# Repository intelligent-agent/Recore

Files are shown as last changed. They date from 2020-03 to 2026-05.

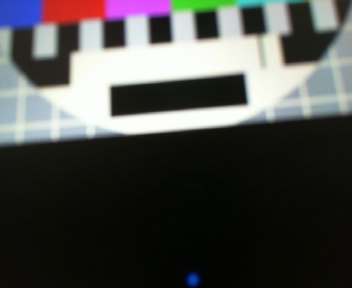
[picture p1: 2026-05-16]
Calibrations/Recore_A8_0449/test_picture.jpg

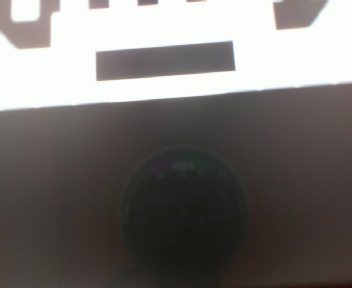
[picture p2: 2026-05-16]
Calibrations/Recore_A8_0461/test_picture.jpg

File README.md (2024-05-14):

# Recore
Repository for Recore 3D printer control board

## What is in here?
- Schematics for Recore etc.
- 3D models of Recore
- Device tree sources
- Special binaries for booting the board in FEL mode
- Calibration and testing data from the manufacturing process

## Note about binaries
There are binaries for booting the board in FEL mode with a
USB drive insered. This method bypasses the eMMC completely.
The three files
- sunxi-spl.bin
- bl31.bin
- u-boot.bin

are used to boot a board in FEL mode. See Makefile
for instructions to use those for a specific revision.

The file `configs/recore_fel_config` is used to compile the new u-boot binaries, 
it is based on u-boot-v2022.07. 

## Sources
The binaries are identical to the what is used in Refactor/Rebuild distro,
the source code is available here:  
https://github.com/intelligent-agent/u-boot and  
https://github.com/intelligent-agent/arm-trusted-firmware  
The only differece is the boot command. In the stock image:  
`run distro_bootcmd`  
in the FEL binaries:   
`run bootcmd_usb0`

## Installing the sunxi-tools package. 
In order to boot the board from FEL-mode, the program `sunxi-fel` must be available. 
In recent versions of Debian (Bookworm and later) and derivatives, this can be installed from apt. 
```
sudo apt install sunxi-tools
```
On older versions of Debian, the sunxi-tools package does not have support for Allwinner A64. 
If that is the case, the program can be downloaded and installed with these instructions:
```
git clone https://github.com/linux-sunxi/sunxi-tools
cd sunxi-tools
make
sudo make install
```

## Starting the board in FEL-mode
Hold down the button marked `fel` while applying power.
The PMIC/power LED should come on. The board must be connected to a host computer through the USB C connector. When the board is in FEL-mode, it should show up as
a USB device on the host computer:  
`lsusb`  
should show:  
`Allwinner Technology sunxi SoC OTG connector in FEL/flashing mode`

Then use the Makefile to run:  
`make fel`

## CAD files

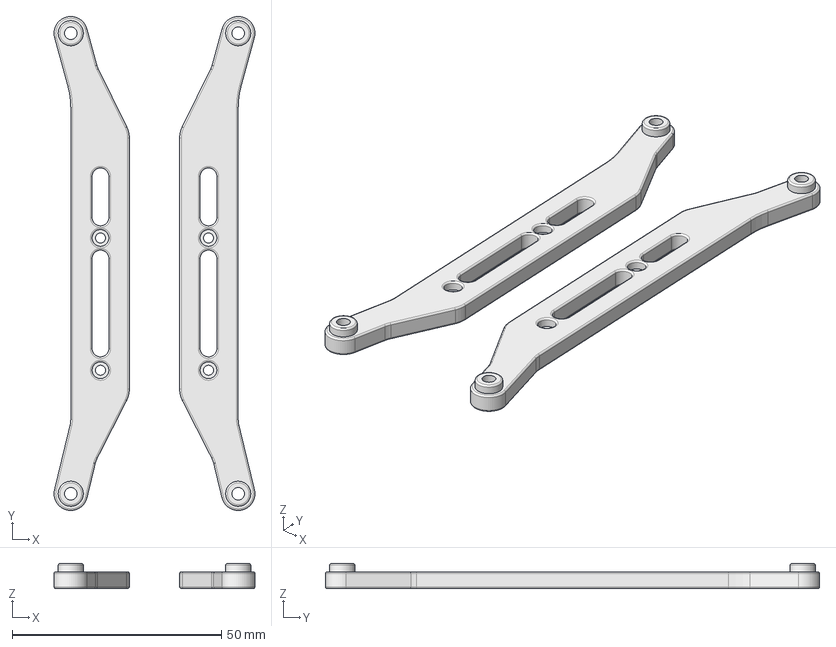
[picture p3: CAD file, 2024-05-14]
3D-files/Rebase/Rebase_A0_din-rail-holders.step
48.0 x 118.0 x 6.00 mm

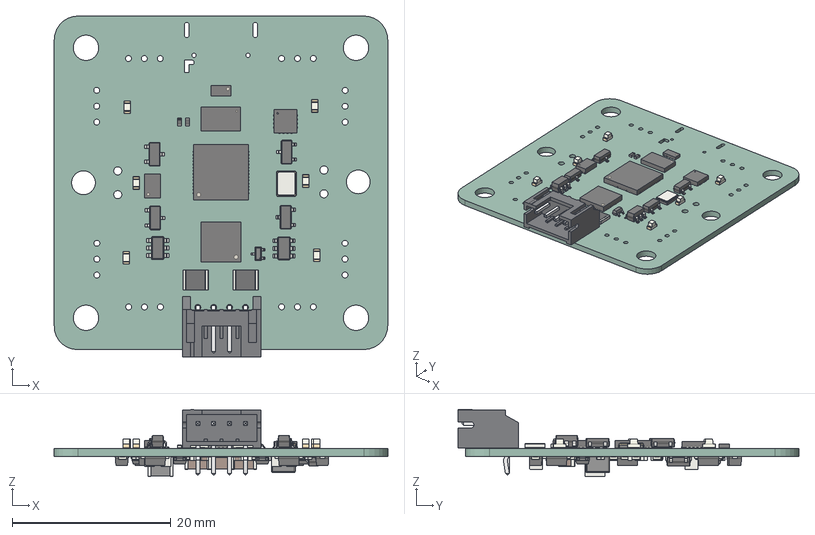
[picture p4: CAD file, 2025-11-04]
3D-files/Retool_A2.step
42.0 x 42.9 x 8.45 mm
DFN-8-1EP_3x2mm_P0.5mm_EP1.7x1.6mm
QFN-56-1EP_7x7mm_Pitch0.4mm
Crystal_SMD_3225-4Pin_3.2x2.5mm
LED_0603_1608Metric x 6
JST_S4B_PH_K
LGA_14_3x5mm_P08mm_LayoutBorder1x6y
R_0402_1005Metric x 42
R_1210_3225Metric x 3
QFN-28-1EP_5x5mm_Pitch0.5mm
SOT_23 x 5
SOT_23_6 x 2
WQFN_16_1EP_3x3mm_P05mm_EP16x16mm
UDFN_10_135x26mm_Pitch05mm
C_1206_3216Metric x 3
C_0402_1005Metric x 37
C_0805_2012Metric x 4
D_SOD_123F x 9
SOT_563
L_Wuerth_MAPI_3020
L_1210_3225Metric
Retool_PCB

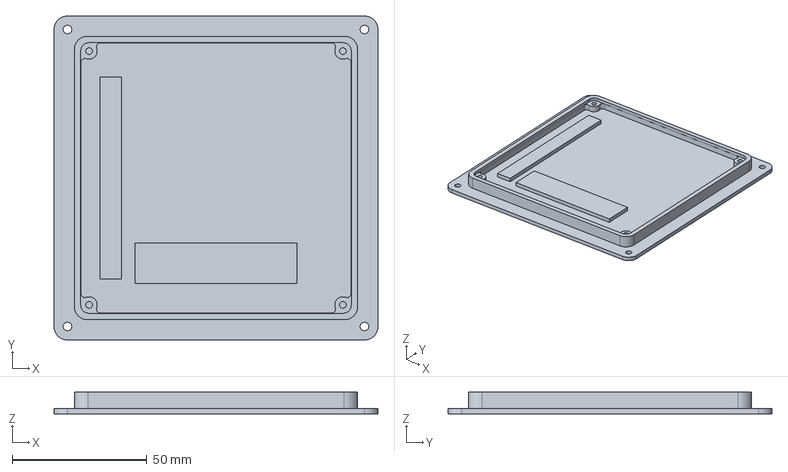
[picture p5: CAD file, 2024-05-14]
3D-files/Rebase/Rebase_A0.step
120.0 x 120.0 x 8.00 mm

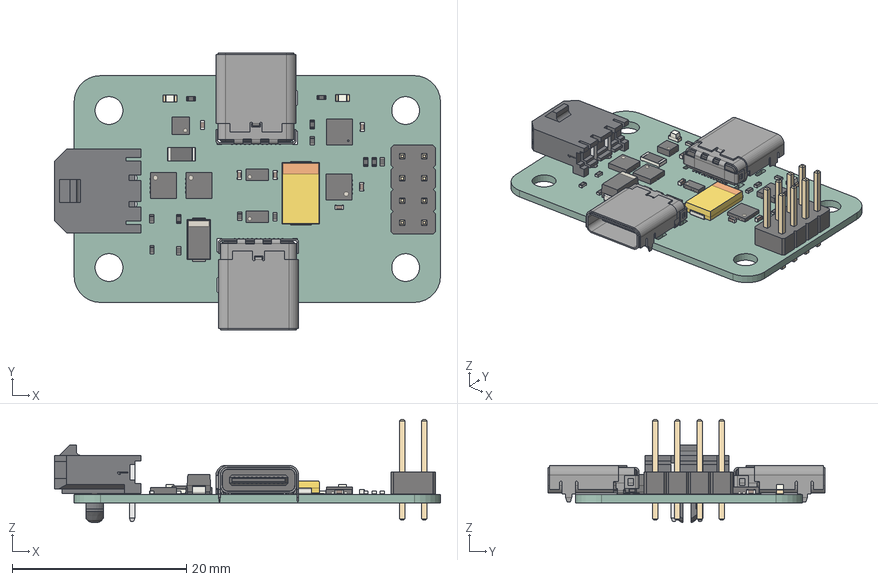
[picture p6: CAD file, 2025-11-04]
3D-files/Resend_A2.step
44.2 x 31.8 x 11.8 mm
C_0402_1005Metric x 6
LED_0603_1608Metric x 2
DFN-8-1EP_3x3mm_Pitch0.5mm x 2
UDFN_10_135x26mm_Pitch05mm x 2
R_0402_1005Metric x 13
WQFN_16_1EP_3x3mm_P05mm_EP16x16mm
DFN-8-1EP_2x2mm_Pitch0.5mm
USB_C_Receptacle_Amphenol_12401610E4-2A x 2
PinHeader_2x04_P254mm_Vertical
R_1206_3216Metric
UQFN-16-1EP_3x3mm_Pitch0.5mm
CP_EIA_7343_15_Kemet_W
D_SMA
_autosave-Resend_PCB

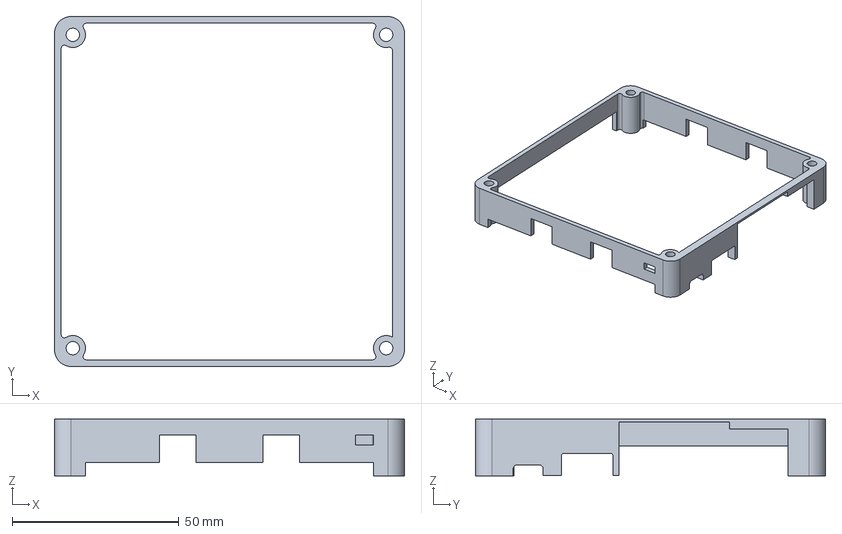
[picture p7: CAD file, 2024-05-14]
3D-files/Rebase/Rebase_A0-ABS-cover.step
105.0 x 105.0 x 17.0 mm

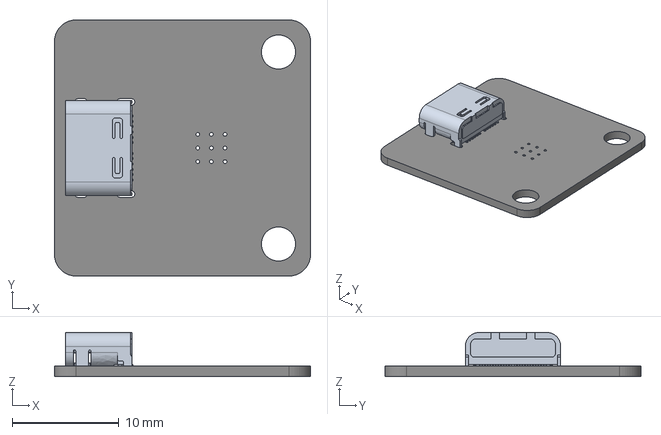
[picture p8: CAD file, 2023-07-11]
3D-files/Remove_A1.step
24.0 x 24.0 x 4.13 mm
Remove_A1 PCB

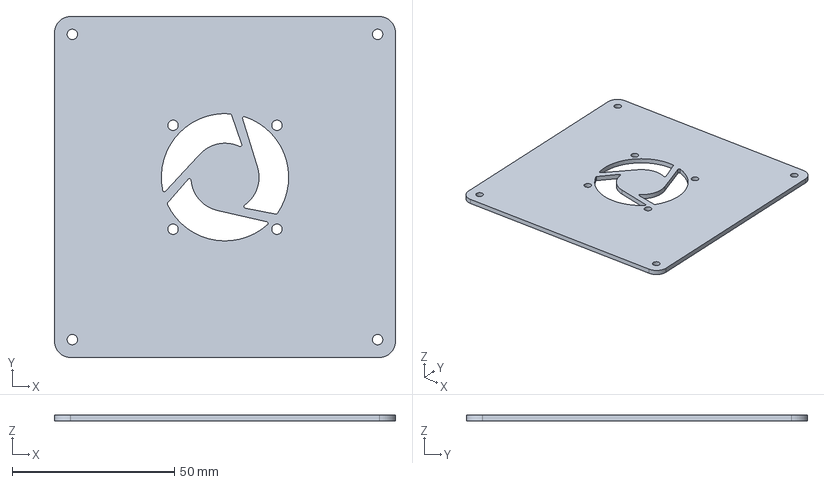
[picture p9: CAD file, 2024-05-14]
3D-files/Rebase/Rebase_A0-acrylic-lid.step
105.0 x 105.0 x 2.00 mm

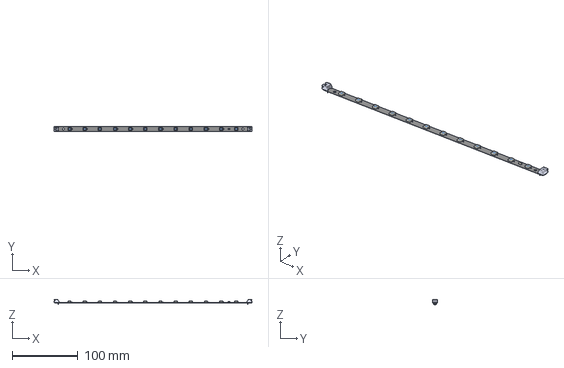
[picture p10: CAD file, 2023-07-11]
3D-files/Relit_A0.step
301.0 x 8.01 x 8.20 mm
_autosave-Relit_A0 PCB

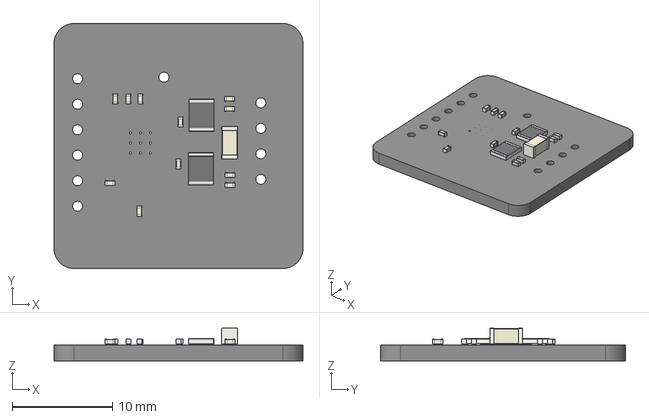
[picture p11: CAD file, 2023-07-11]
3D-files/Restep_A1.step
24.8 x 24.4 x 3.25 mm
Restep_A1 PCB

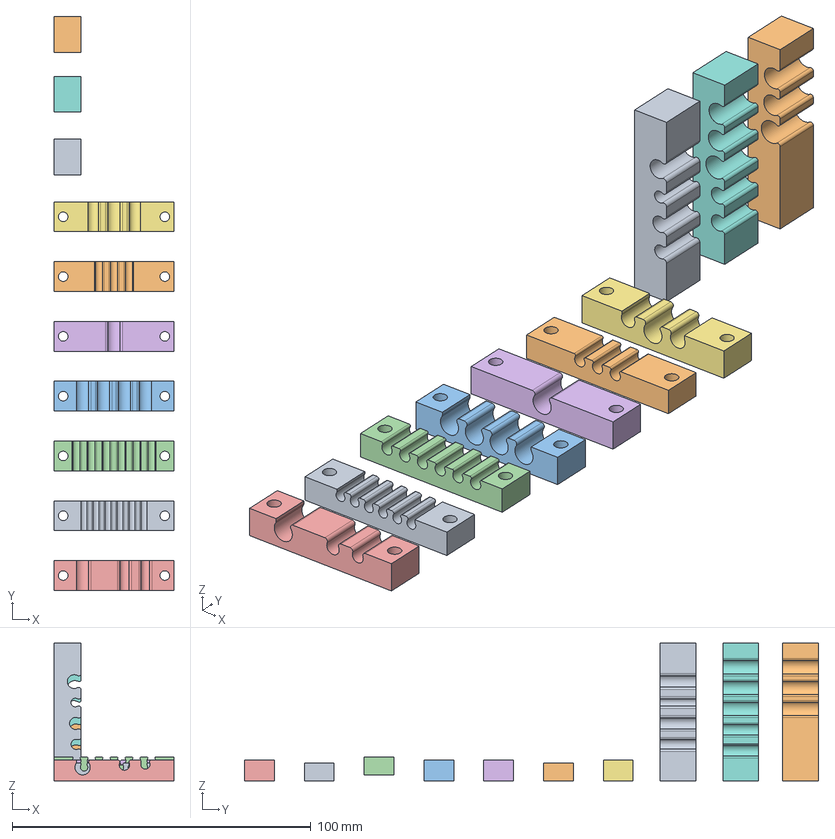
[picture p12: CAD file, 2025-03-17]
3D-files/Voron-2.4/Clamps/Clamps.FCStd
40.0 x 192.0 x 46.0 mm
Wires-6-24V
Wires-3-220V
Steppers-4-wires
Wires-6-220V
Wires-Stepper-camera-Relit
Wires-Stepper
Wires-back
Wires-3xUSB-2xFan-Eth
Wires-2xUSB-HDMI-2xFan
Wires-USB-USB-Eth

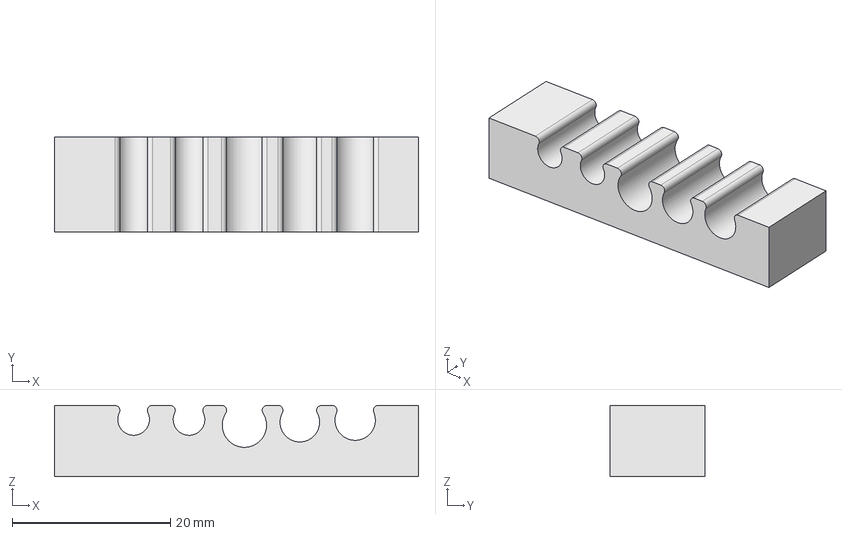
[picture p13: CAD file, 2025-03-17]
3D-files/Voron-2.4/Clamps/Wires-3xUSB-2xFan-Eth.step
46.0 x 12.0 x 9.00 mm

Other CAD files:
3D-files/Voron-2.4/Clamps/Wires-2xUSB-HDMI-2xFan.step
3D-files/Voron-2.4/Clamps/Wires-USB-USB-Etht.step

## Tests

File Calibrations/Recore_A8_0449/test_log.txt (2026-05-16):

Test starting 2026-03-01 22:23:06.269564
Testing board
Board voltage           [    OK   ]
Current                 [    OK   ]
Board t                 [    OK   ]
Junction t              [    OK   ]
Similarity              [    OK   ]
Thermistor Off voltage  [    OK   ]
Thermistor On voltage   [    OK   ]
ES1 Off voltage         [    OK   ]
ES1 On voltage          [    OK   ]
ES0 off voltage         [    OK   ]
ES0 on voltage          [    OK   ]
ES0 12V value           [    OK   ]
USB host 0 on           [    OK   ]
USB host 1 on           [    OK   ]
USB host 2 on           [    OK   ]
USB host 3 on           [    OK   ]
FEL voltage             [    OK   ]
BOOT voltage            [    OK   ]
RESET voltage           [    OK   ]
HDMI voltage            [    OK   ]
V-HP off                [    OK   ]
Testing motors
Stepper 0 comm          [    OK   ]
Stepper 1 comm          [    OK   ]
Stepper 2 comm          [    OK   ]
Stepper 3 comm          [    OK   ]
Stepper 4 comm          [    OK   ]
Stepper 5 comm          [    OK   ]
Stepper 0 driver        [    OK   ]
Stepper 1 driver        [    OK   ]
Stepper 2 driver        [    OK   ]
Stepper 3 driver        [    OK   ]
Stepper 4 driver        [    OK   ]
Stepper 5 driver        [    OK   ]
Testing heaters
Heater H0 on            [    OK   ]
Heater H0 off           [    OK   ]
Heater H1 on            [    OK   ]
Heater H1 off           [    OK   ]
Heater H2 on            [    OK   ]
Heater H2 off           [    OK   ]
Heater BED on           [    OK   ]
Heater BED off          [    OK   ]
Heater Fan 0 on         [    OK   ]
Heater Fan 0 off        [    OK   ]
Heater Fan 1 on         [    OK   ]
Heater Fan 1 off        [    OK   ]
Heater Fan 2 on         [    OK   ]
Heater Fan 2 off        [    OK   ]
Heater Fan 3 on         [    OK   ]
Heater Fan 3 off        [    OK   ]
Testing USB
Devices                 [    OK   ]
USB host 0 on           [    OK   ]
USB host 1 on           [    OK   ]
USB host 2 on           [    OK   ]
USB host 3 on           [    OK   ]
Testing Ethernet
Ethernet                [    OK   ]
Testing voltages
VS                      [    OK   ]
GND BOARD               [    OK   ]
12V JIG                 [    OK   ]
GND JIG                 [    OK   ]
V HP                    [    OK   ]
3.3V_VREF               [    OK   ]
1.05V_ETH               [    OK   ]
3.3V_AREF               [    OK   ]
ADC-V                   [    OK   ]
ADC-T                   [    OK   ]
ADC-I                   [    OK   ]
0.6V_CMPREF             [    OK   ]
1.8-VINT                [    OK   ]
3.3V-VA                 [    OK   ]
3.0V-PLL                [    OK   ]
3.0V-RTC                [    OK   ]
+12V                    [    OK   ]
1.1V-CPUS               [    OK   ]
1.25V-VREF              [    OK   ]
1.2V-CPUX               [    OK   ]
1.35V-DDR3              [    OK   ]
1.8V-EMMC               [    OK   ]
3.3-HDMI                [    OK   ]
1.1V-SYS                [    OK   ]
+5V                     [    OK   ]
3.3V                    [    OK   ]
VS                      [    OK   ]
Testing op-amp offset
Opamp T0, offset on     [    OK   ]
Opamp T0, offset off    [    OK   ]
Opamp T1, offset on     [    OK   ]
Opamp T1, offset off    [    OK   ]
Opamp T2, offset on     [    OK   ]
Opamp T2, offset off    [    OK   ]
Opamp T3, offset on     [    OK   ]
Opamp T3, offset off    [    OK   ]
Testing op-amp gain
Opamp T0, gain 1        [    OK   ]
Opamp T0, offset 0.0002 [    OK   ]
ADC diff T0 is 0.025    [    OK   ]
Opamp T0, gain 100      [    OK   ]
Opamp T0, offset 0.33   [    OK   ]
ADC diff T0 is 0.025    [    OK   ]
Opamp T1, gain 1        [    OK   ]
Opamp T1, offset 0.0002 [    OK   ]
ADC diff T1 is 0.025    [    OK   ]
Opamp T1, gain 100      [    OK   ]
Opamp T1, offset 0.33   [    OK   ]
ADC diff T1 is 0.025    [    OK   ]
Opamp T2, gain 1        [    OK   ]
Opamp T2, offset 0.0002 [    OK   ]
ADC diff T2 is 0.025    [    OK   ]
Opamp T2, gain 100      [    OK   ]
Opamp T2, offset 0.33   [    OK   ]
ADC diff T2 is 0.025    [    OK   ]
Opamp T3, gain 1        [    OK   ]
Opamp T3, offset 0.0002 [    OK   ]
ADC diff T3 is 0.025    [    OK   ]
Opamp T3, gain 100      [    OK   ]
Opamp T3, offset 0.33   [    OK   ]
ADC diff T3 is 0.025    [    OK   ]
Testing op-amp resistors
Resistor T0 pull-up     [    OK   ]
Resistor T0 offset      [    OK   ]
Resistor T1 pull-up     [    OK   ]
Resistor T1 offset      [    OK   ]
Resistor T2 pull-up     [    OK   ]
Resistor T2 offset      [    OK   ]
Resistor T3 pull-up     [    OK   ]
Resistor T3 offset      [    OK   ]
Testing Recore
Recore                  [    OK   ]

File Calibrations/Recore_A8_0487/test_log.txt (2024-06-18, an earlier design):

Test starting 2024-06-18 20:45:25.012450
Testing board
Board voltage           [    OK   ]

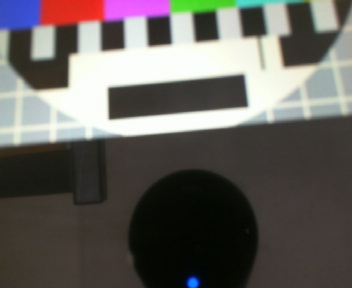
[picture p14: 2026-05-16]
Calibrations/Recore_A8_0453/test_picture.jpg

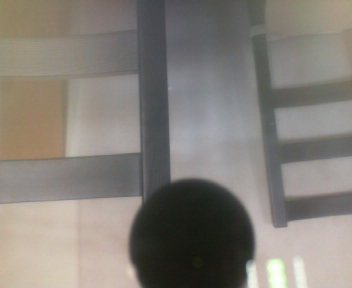
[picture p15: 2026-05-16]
Calibrations/Recore_A8_0452/test_picture.jpg

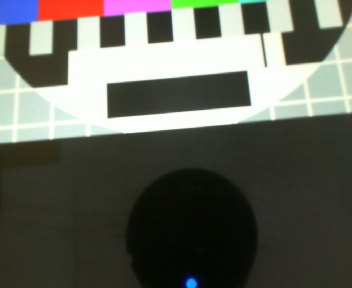
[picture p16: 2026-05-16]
Calibrations/Recore_A8_0466/test_picture.jpg

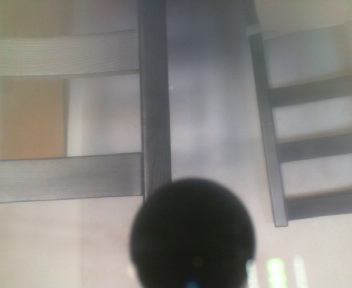
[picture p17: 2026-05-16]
Calibrations/Recore_A8_0460/test_picture.jpg

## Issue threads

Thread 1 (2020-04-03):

Assistance Desired?

Casey7747, 2020-04-03:
Hi Elias,
I have been following your revolve project as I am in the process of putting a new printer together and hoped to use your controller.

How are you traveling with the latest iteration, Recore? Would you like some help?
I am very familiar with Linux, python programming/scripting + arduino + elec design at a hobby level. I am an automation engineer by profession designing programming PLC etc. So I may be of some help.

I would think helping you in testing would be my greatest assistance but I don't think you are there yet. I can also do debugging and maybe simulations?

Let me know if you think I could help.

Regards
Felix

eliasbakken, 2020-04-04:
Hi Felix! Thanks a lot for your enthusiasm : )

To answer your question: Yes, help is needed, but it's really on the software side that you can contribute. I've put together a couple of boards so far, that are intended for some of the people that have been in the (replicape) community for a long time, so they have dibs. I'm hoping to get a small batch of around ten boards made based on their feedback and my own testing.

I'm planning to sell the first 10 board batch for a normal price, so it's really intedid for those with a special interest in early access to the hardware. Later batches will have better software support and probably some hardware changes as well.

Those Rev A2 boards should be going out this week, and we discuss most of the details in #development channel on replicape.slack.com

Casey7747, 2020-04-05:
Thanks,
I have emailed you re: slack.

Closed 2020-04-05.

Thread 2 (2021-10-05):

CAD model discrepancies

eliasbakken, 2021-10-05:
The USB is 1 mm too high and the HDMI is 1 mm loo low.

eliasbakken, 2022-01-13:
The model has been updated and should be pretty accurate. I measured the height of the USB and HDMI, but only adjusted the HDMI with 0.5 mm.

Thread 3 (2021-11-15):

Hello and Setting the Recore for Printing on the Older Model Printer I have Currently...

silver2row, 2021-11-15:
Hello,

Seth here. @eliasbakken and @goeland86 , this is Seth or known as silver2row on support-recore on Discord.

Anyway, enough w/ names for now.

Can I use the 12v pin on ES0 when using GND and 3.3v on the ES5 pin specifically for the NPN Probe I use?

I am asking b/c I did not know if there was a bridge or bar of a GND on that specific side of the Recore. I do not want to catch static or error when trying to wire up like this idea on the Recore. If this does not make sense, I completely understand. I can try to better make sense in time.

...

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

...

I see where the ES0 connection on the wiki is 5v/12v and can be picked to either/or. But, in the photo I have listed, the ES5 pin is listed as 5v/12v.

I just want to make sure I do not alter the board state permanently by applying GND to a pin outside of its specific connector area.

Seth

P.S. Please do let me know what you have in mind from this issue. I contacted the group on Discord already. If Discord is a better place to handle this issue, that is okay too. I will just wait and try to catch someone.

eliasbakken, 2021-11-15:
Hi Seth,
Discord is probably better for support issues like this. This issue tracker is meant for hardware bugs with Recore boards specifically.  The numbering of the end stops were changed at some point during the development, so I think ES5 switched places with ES0 and so on. So The pinout information in the picture on the wiki is outdated. It is ES0 that has the programmable 5/12V output.

To answer your question, the ground of all the end stops are connected together. so you can use the 12V on EN0 for triggering the input on ES5 for instance. But there should be the right number of of pins to mount an inductive sensor using only ES0.
You mention 3.3V on the ES5, that is not correct. The output is fixed at 5V. So just be aware of that when wiring up.

silver2row, 2021-11-15:
Hello,

Thank you for this update. And okay about the 5v output on ES5. My mistake.

Seth

Closed 2021-11-15.

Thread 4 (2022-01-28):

Add an LED close to the USB hub/connectors to indicate activitiy on the USB.

eliasbakken, 2022-01-28:
On rev A6, the user LED close to the HDMI connector is used to indicate activity on the USB hosts. This is not ideal, since the position of the LED is not related to the function. It would be better if the LED was close to the USB hub chip to match the pattern shown by the other chips.

eliasbakken, 2023-06-28:
This has been fixed on A7.

Closed 2023-06-28.

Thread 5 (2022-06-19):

Recore din rail .step file

Jasontwd, 2022-06-19:
Fusion 360 recore mount and din rail clips if any one needs.  https://a360.co/3N5ySeC

Jasontwd, 2022-06-23:
@tehmaze Hey mate, yes not sure why was not working but is now. Download top right screen.
Lets know if not and I'll email you it.. jason@formtech.co.nz

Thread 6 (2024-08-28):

[Question] What software made this pinout photo?

DjordjeMandic, 2024-08-28:
Hi, im intrested which software did you use to create this pinout photo and other wiring diagrams?

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

eliasbakken, 2024-08-28:
The board is exported from Kicad as step, then imported to Freecad where it is made into a picture and exported as png, then imported to Inkscape where the lables are added.

DjordjeMandic, 2024-08-28:
Thanks, I thought you used something like WireViz or qelectrotech

Closed 2024-08-28.

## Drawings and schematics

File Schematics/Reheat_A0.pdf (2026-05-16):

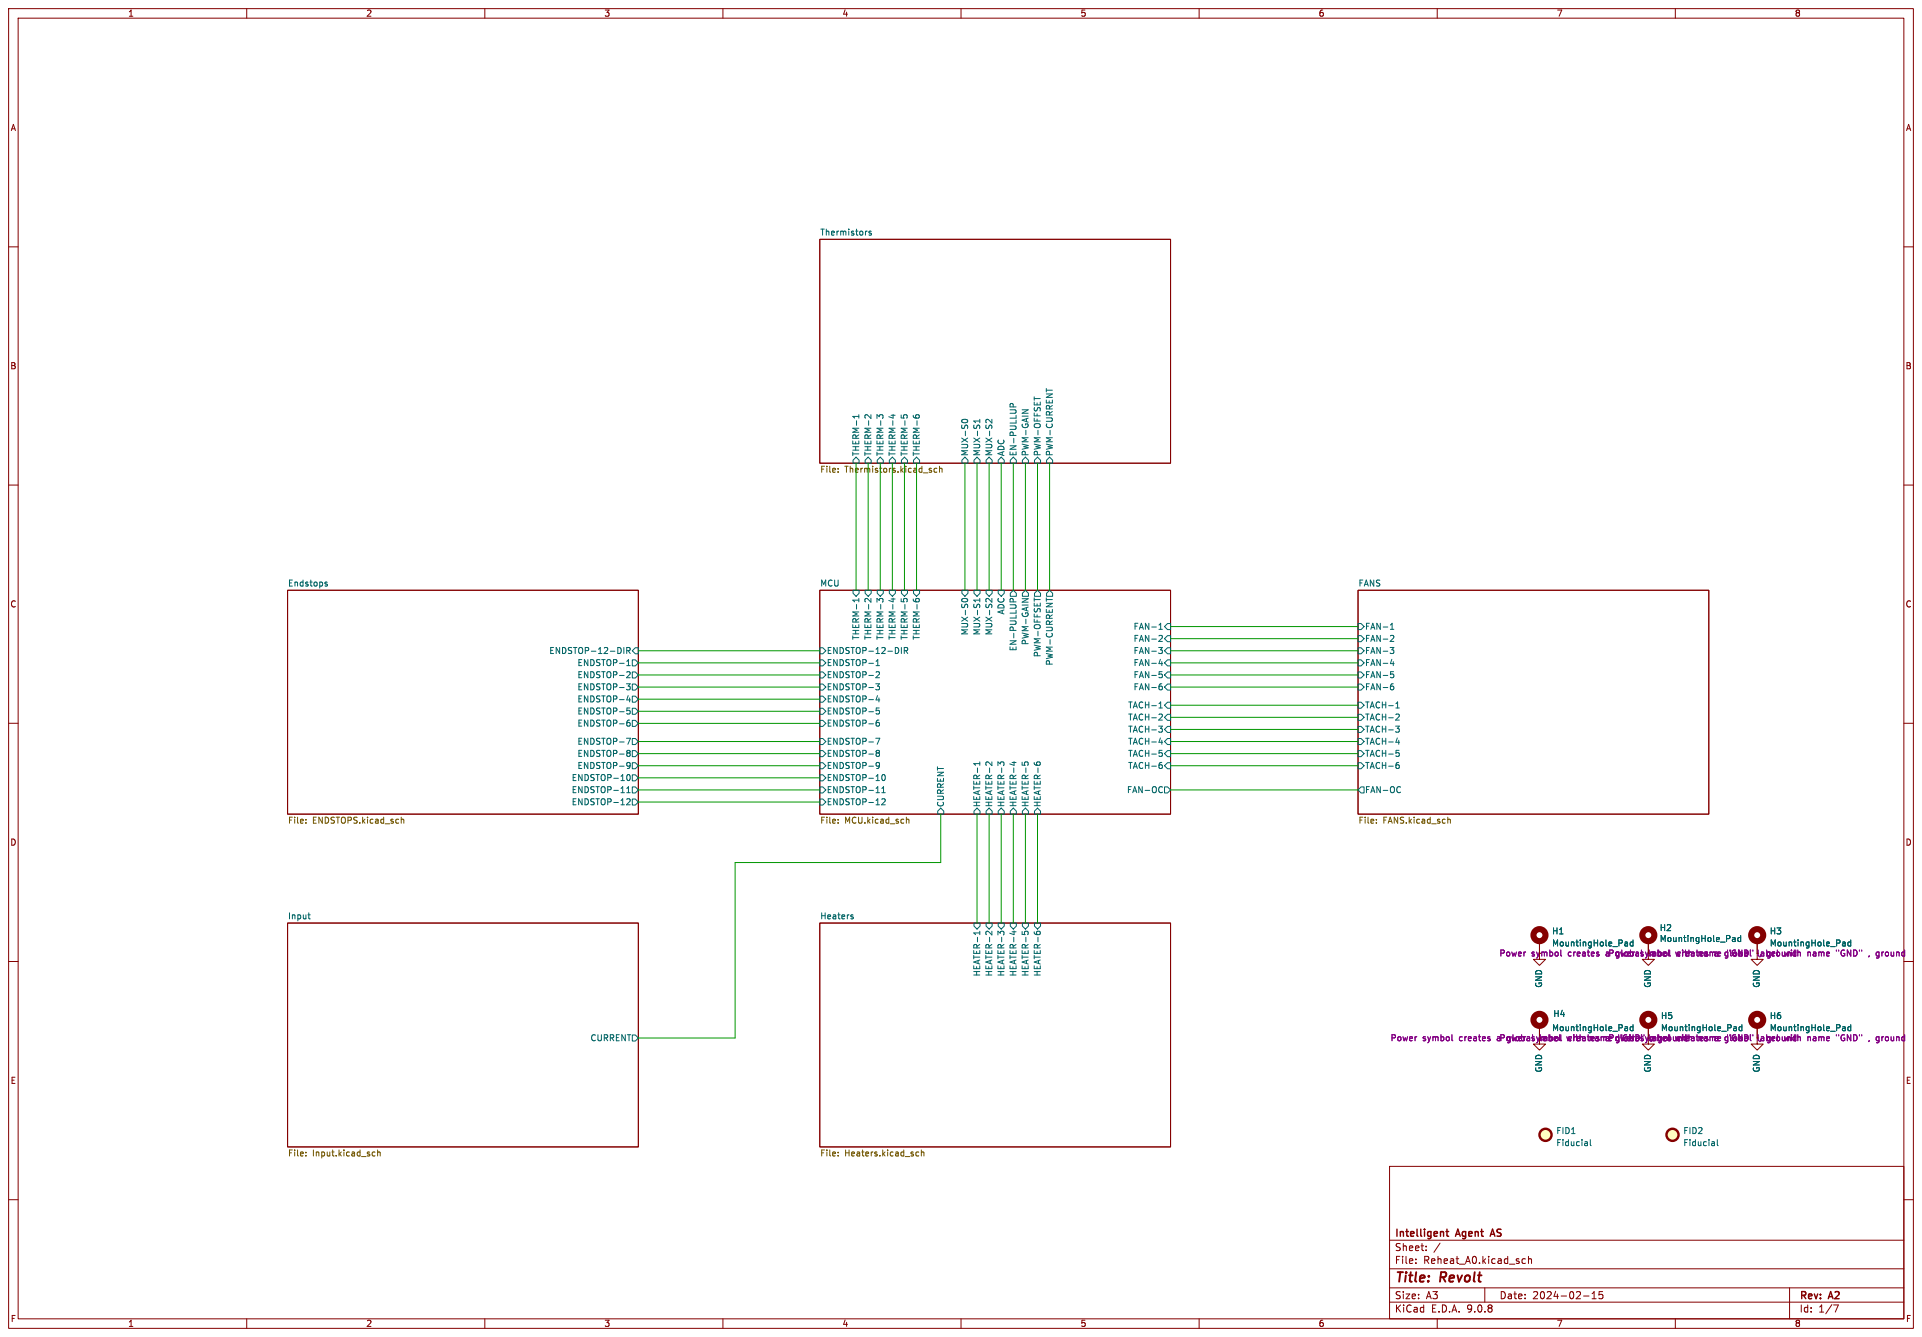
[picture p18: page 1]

ENDSTOP-8 ENDSTOP-6 ENDSTOP-9 ENDSTOP-11 ENDSTOP-7 ENDSTOP-4 ENDSTOP-10 ENDSTOP-3 ENDSTOP-1 ENDSTOP-12 ENDSTOP-5 ENDSTOP-2 ENDSTOP-12-DIR

Power symbol creates a global label with name "GND" , ground H3 MountingHole_Pad H6 MountingHole_Pad GND

Power symbol creates a global label with name "GND" , ground GND GND

Power symbol creates a global label with name "GND" , ground GND

Power symbol creates a global label with name "GND" , ground

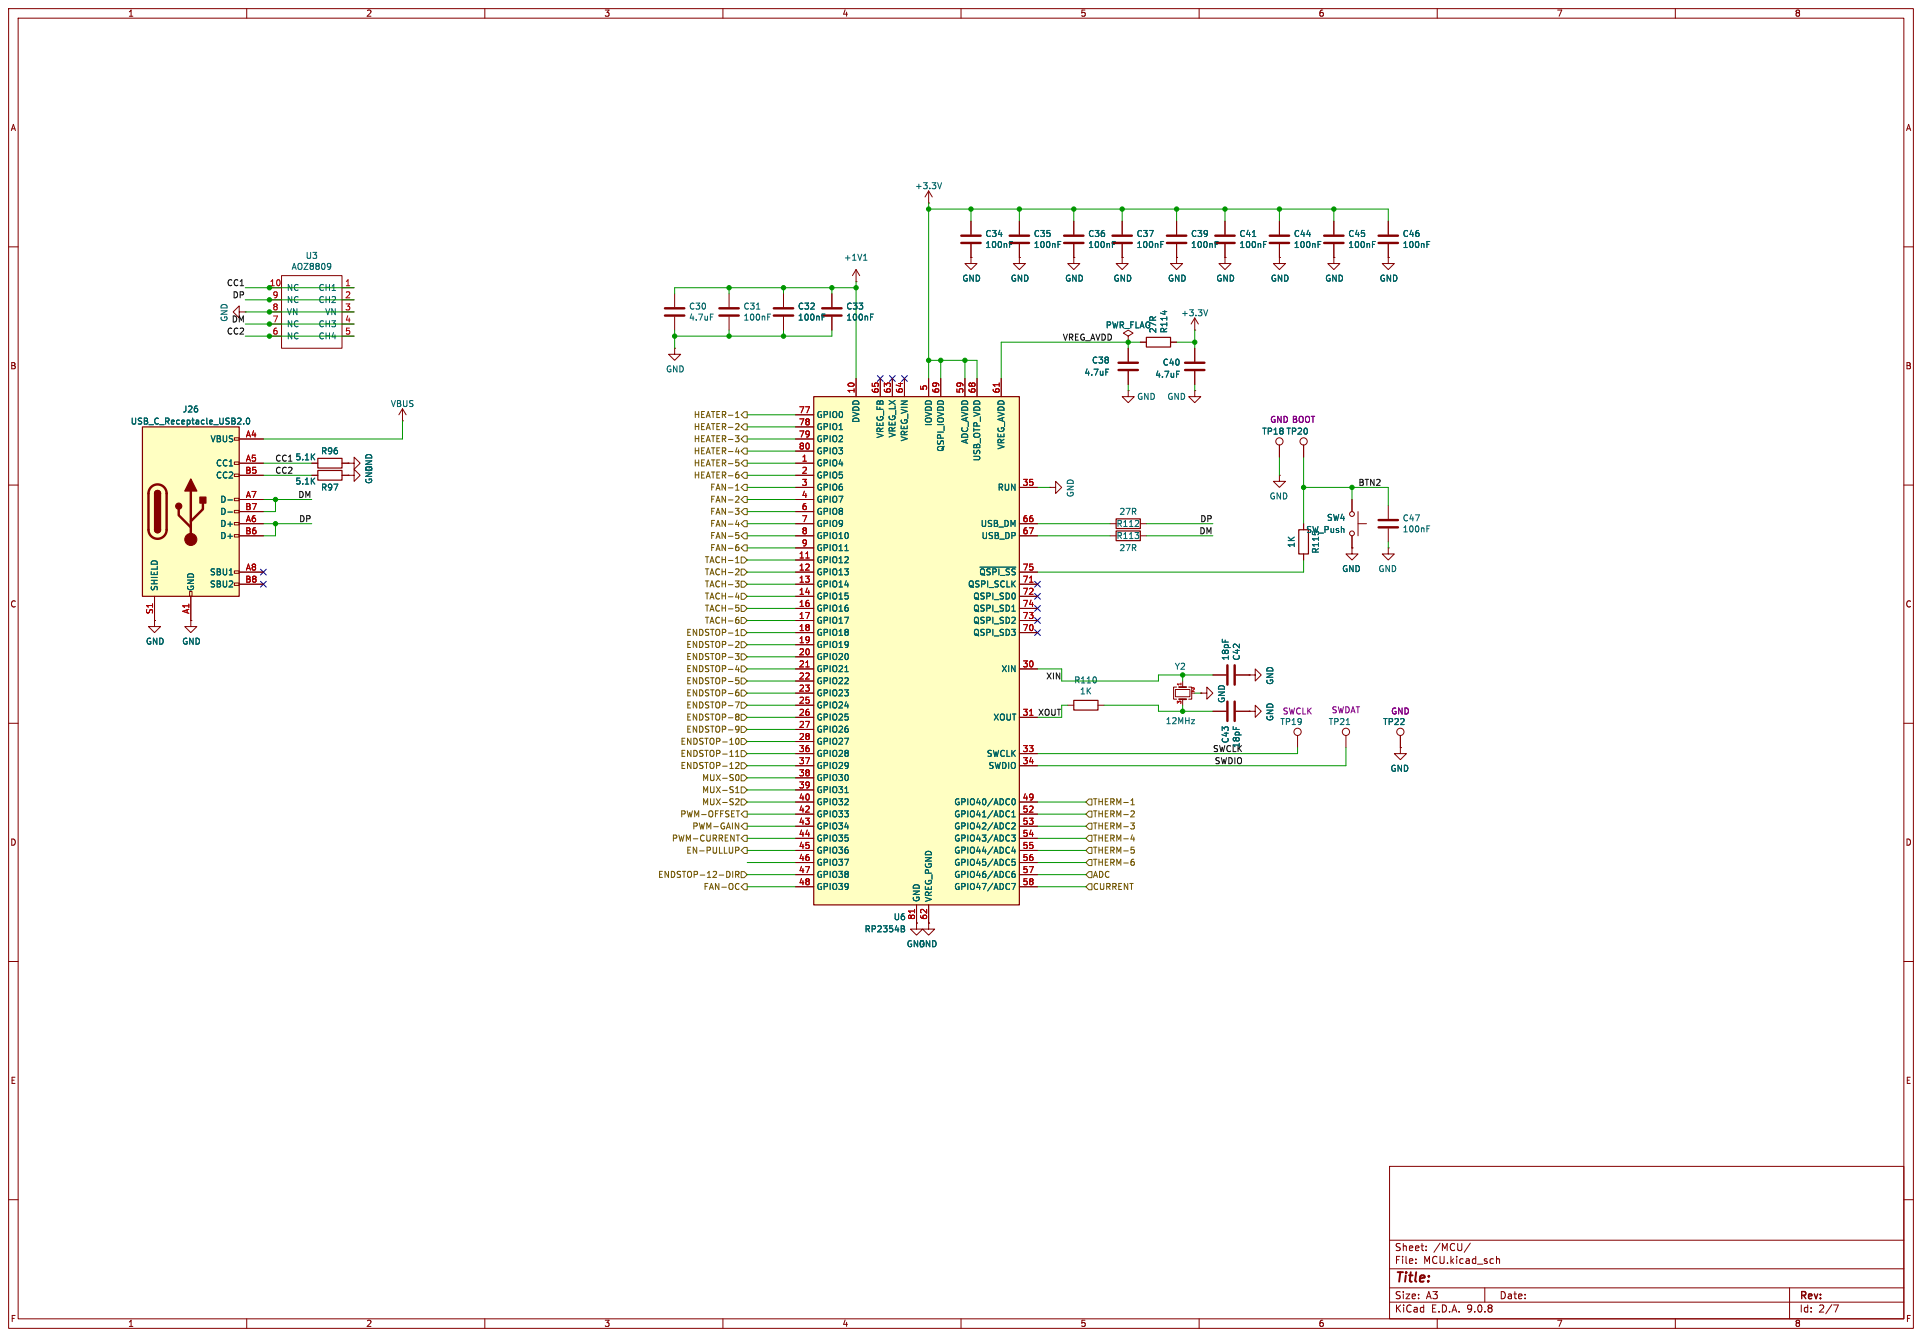
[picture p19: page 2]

TP22 GND GND GND C43 18pF GND

FAN-3 FAN-5 TACH-2 FAN-4 FAN-OC

THERM-4 MUX-S0 PWM-GAIN MUX-S2 MUX-S1 PWM-CURRENT

THERM-3 PWM-OFFSET EN-PULLUP

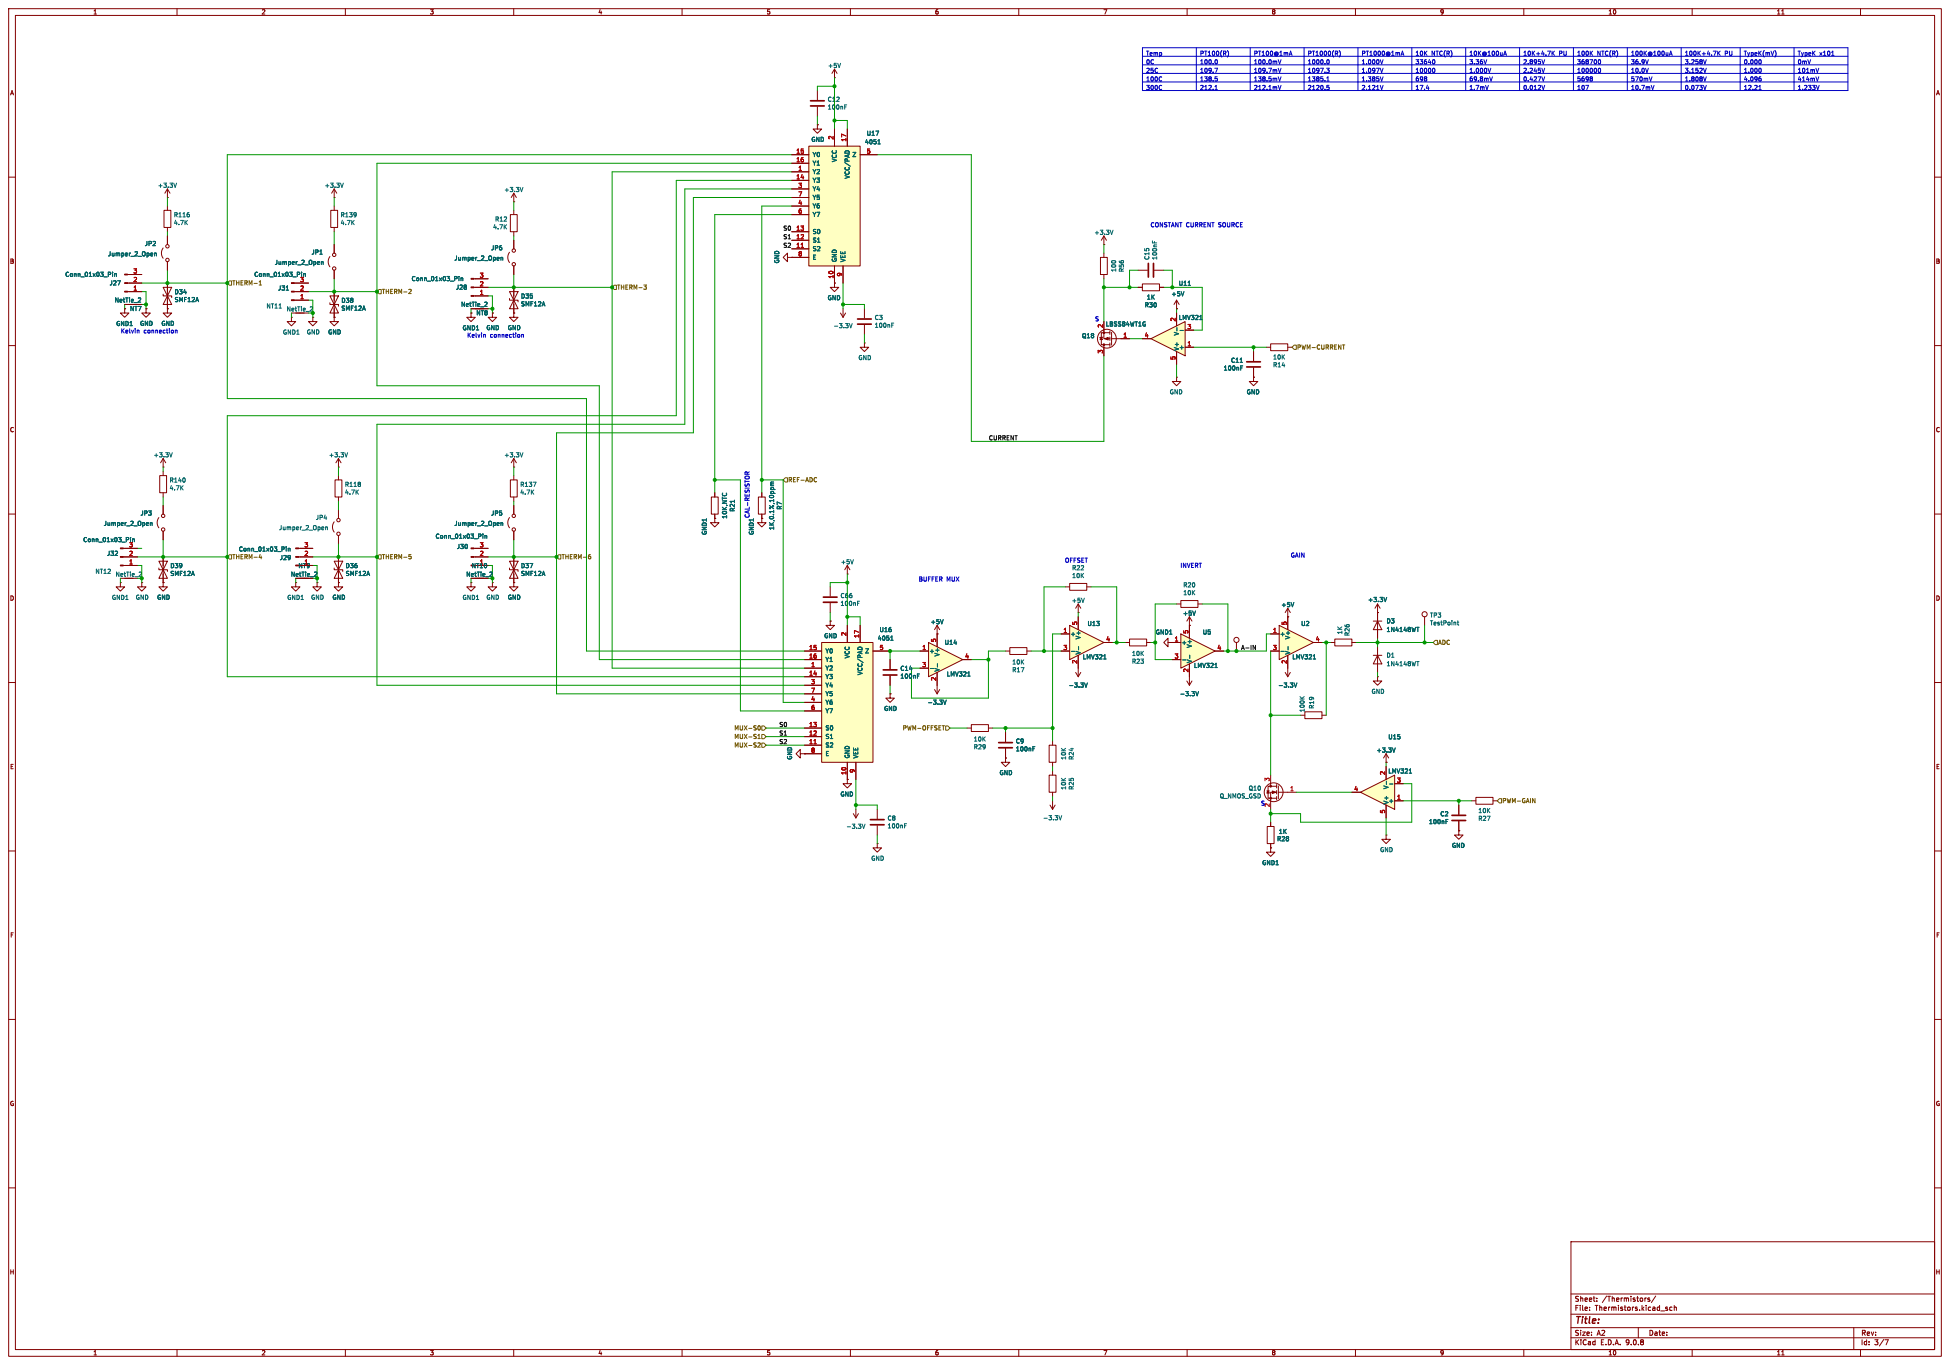
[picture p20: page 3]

CONSTANT CURRENT SOURCE GND GND

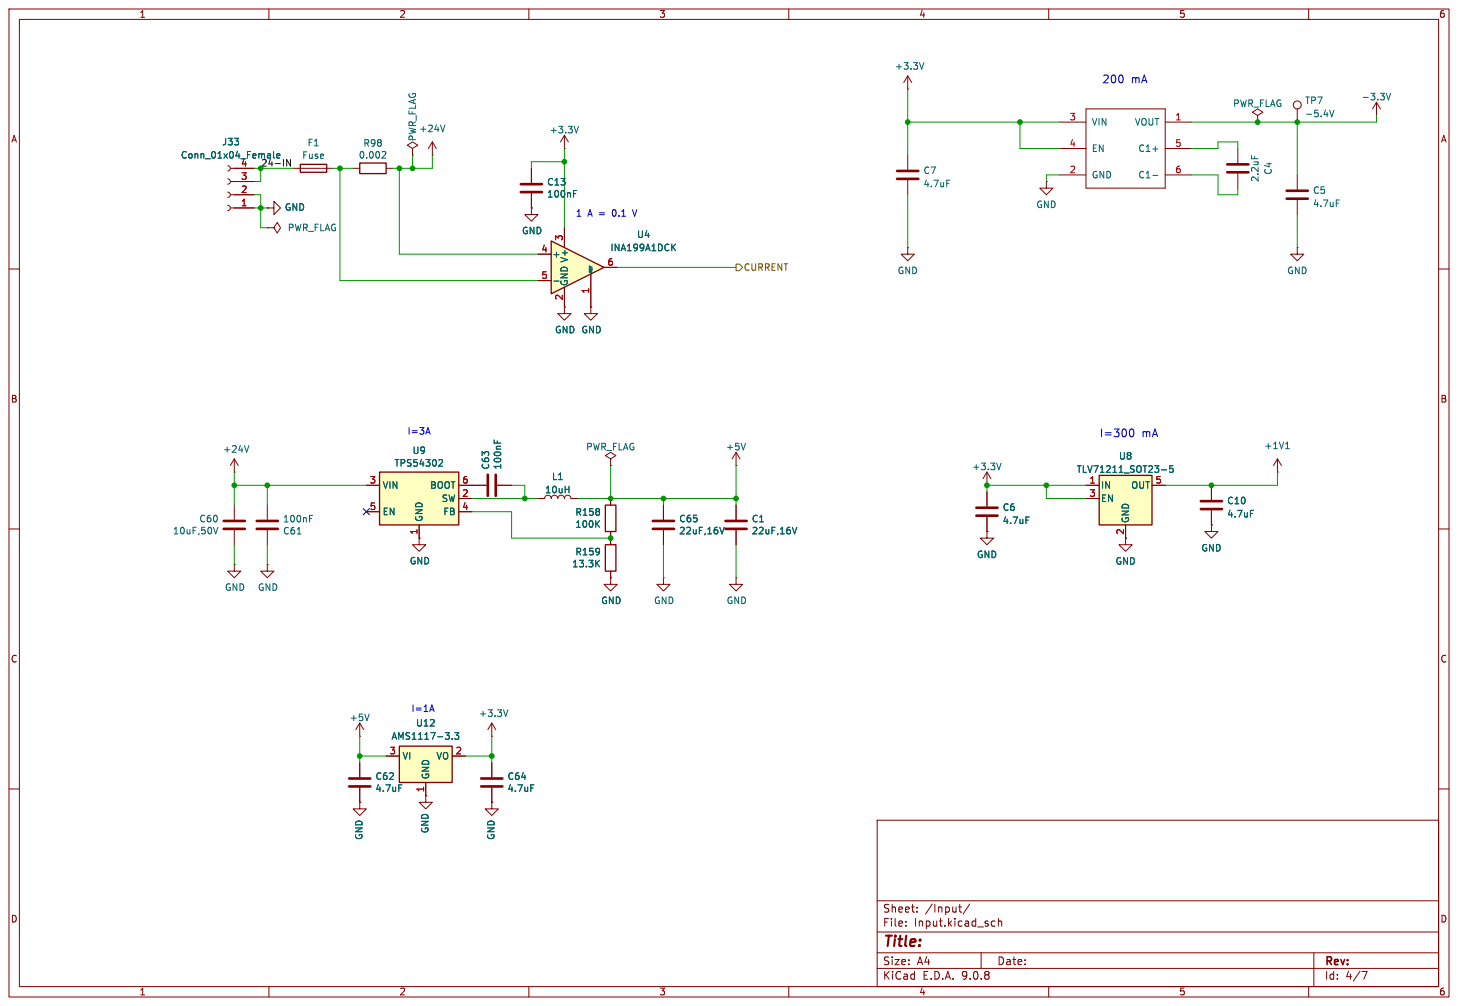
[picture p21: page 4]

1 BOOT 6 SW 2 FB 4 U9 TPS54302 GND GND

1 VO 2 U12 AMS1117-3.3 VIN 3 EN 5 GND

1 BOOT 6 SW 2 FB 4 GND

Id: 4/7 Title: File: Input.kicad_sch Sheet: /Input/

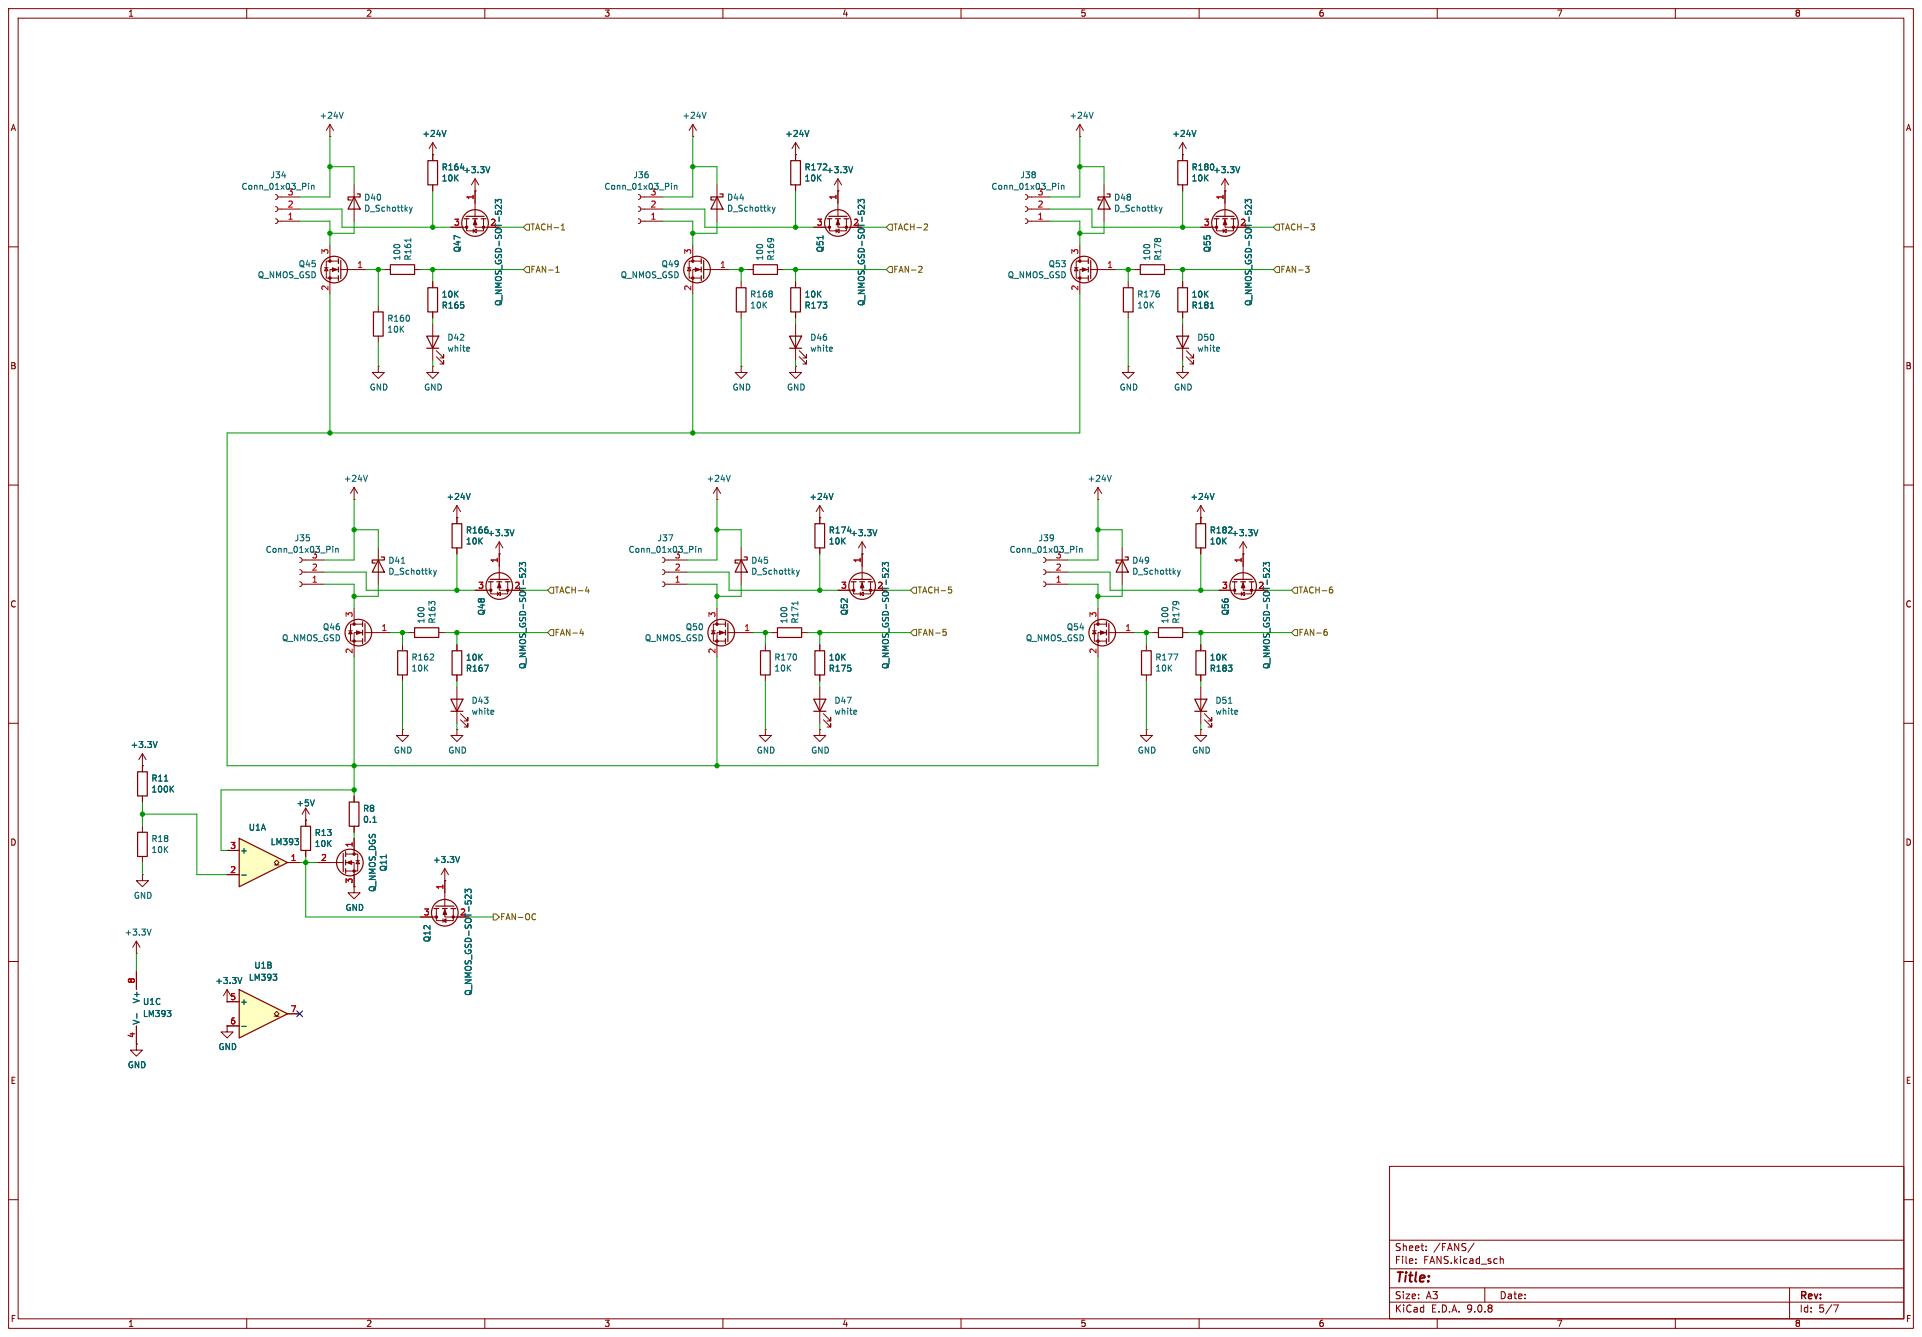
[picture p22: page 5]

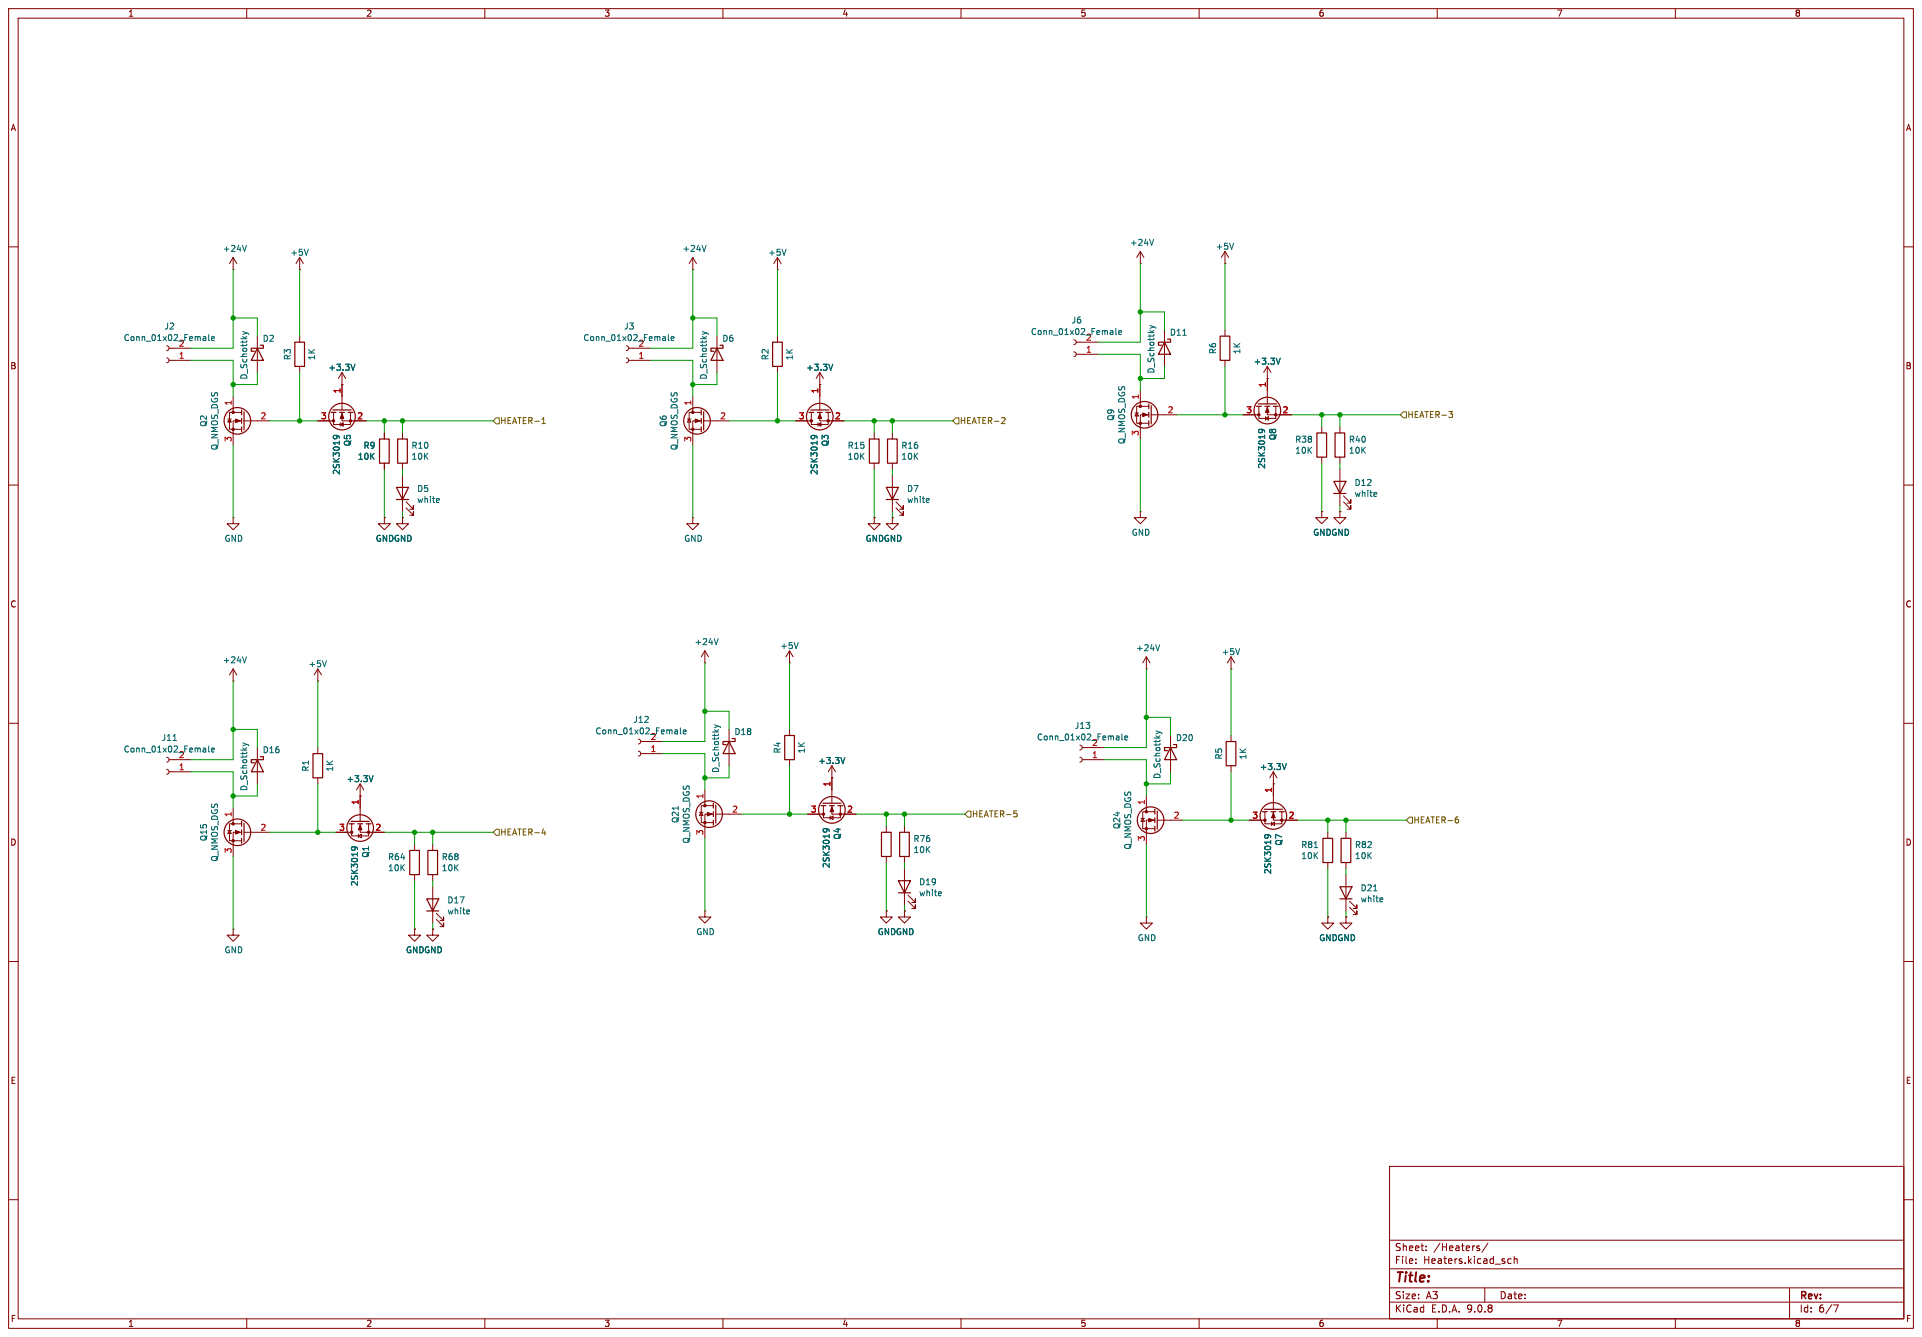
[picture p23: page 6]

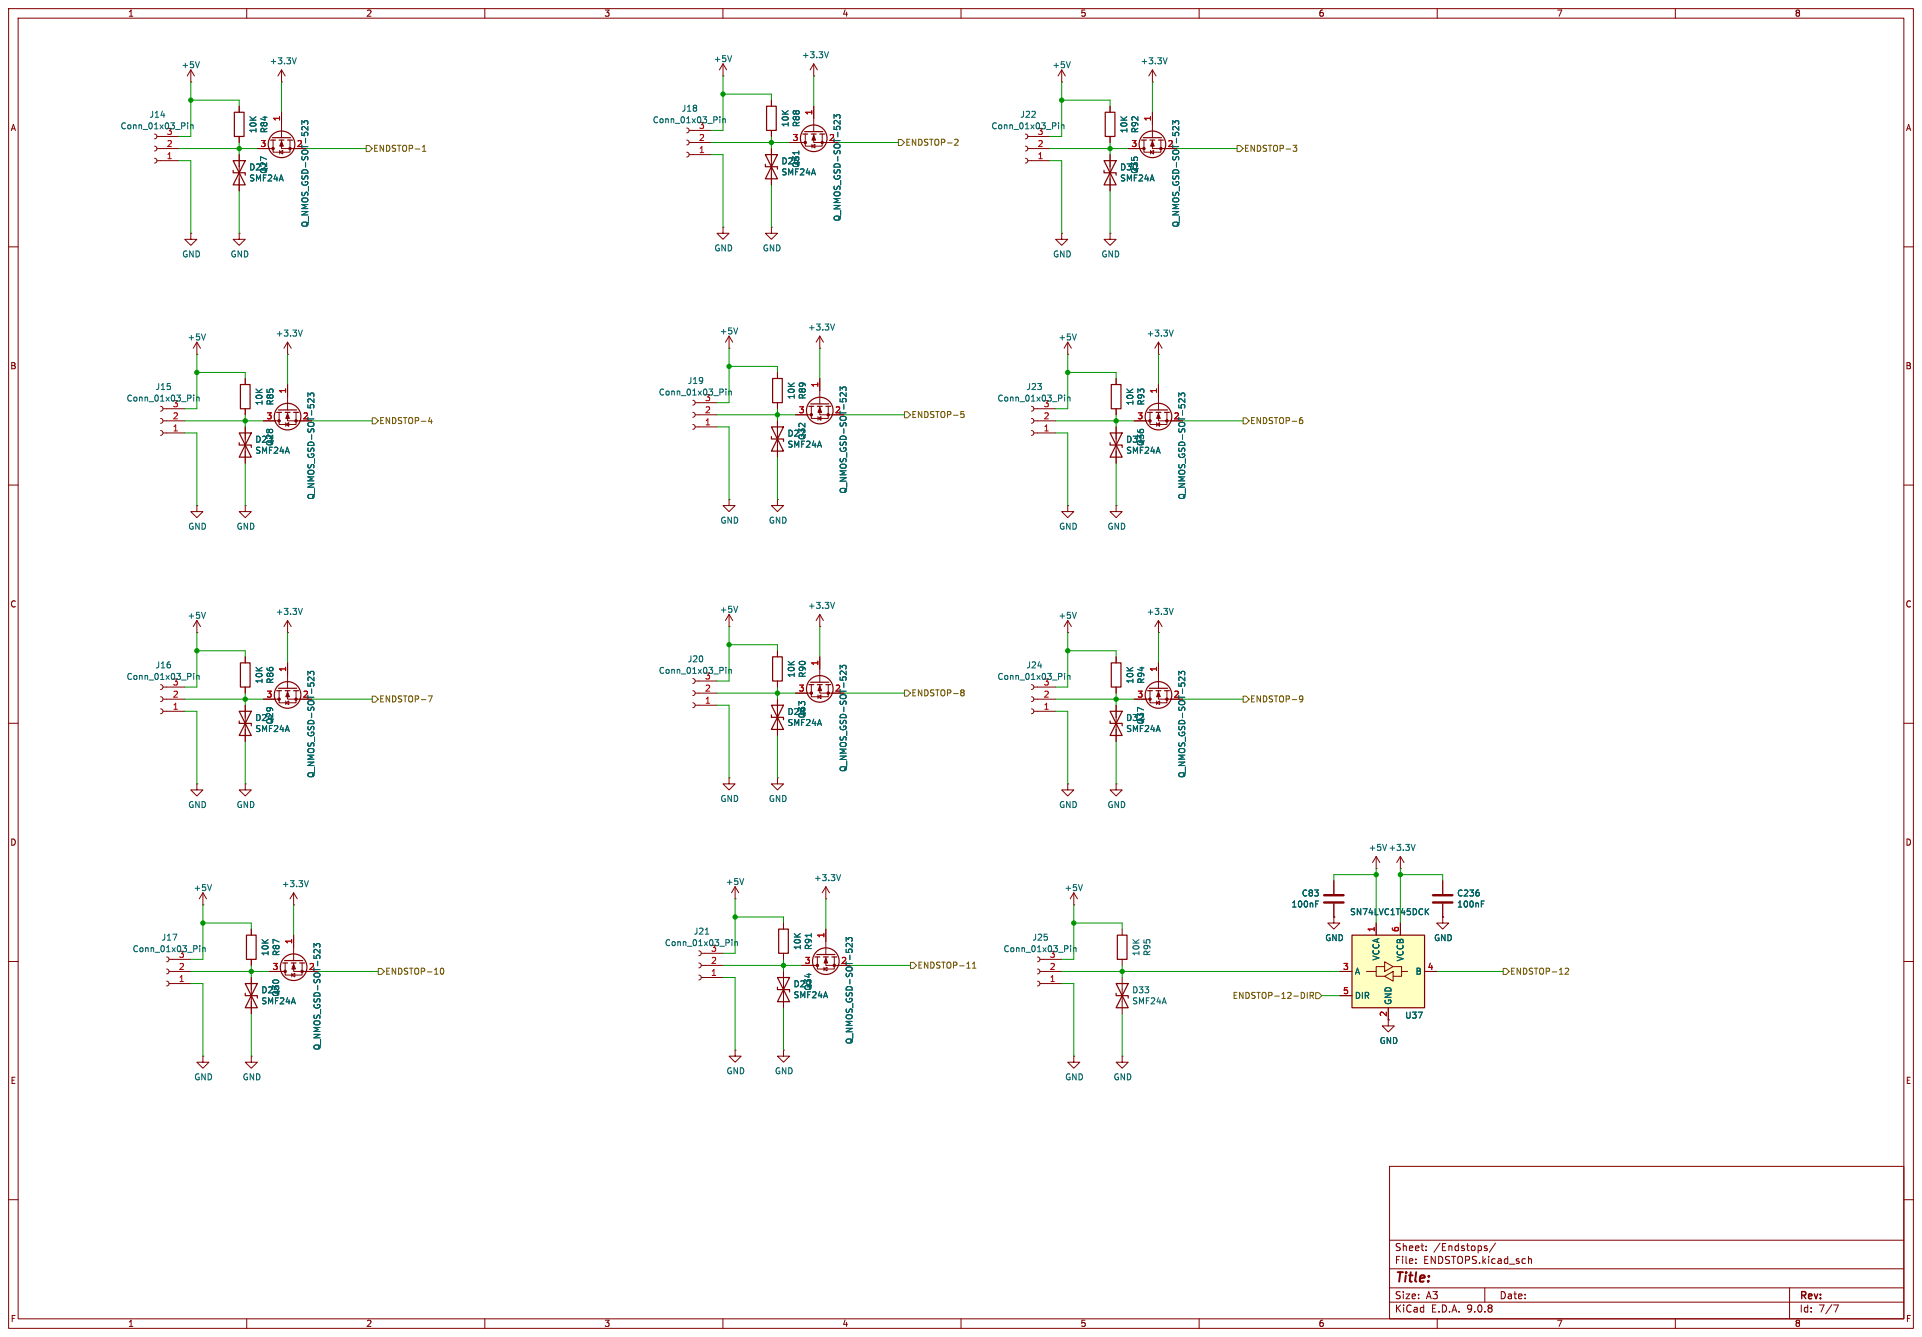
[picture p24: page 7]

ENDSTOP-2 ENDSTOP-1
ENDSTOP-6 ENDSTOP-3 ENDSTOP-9 ENDSTOP-8 ENDSTOP-7 ENDSTOP-10

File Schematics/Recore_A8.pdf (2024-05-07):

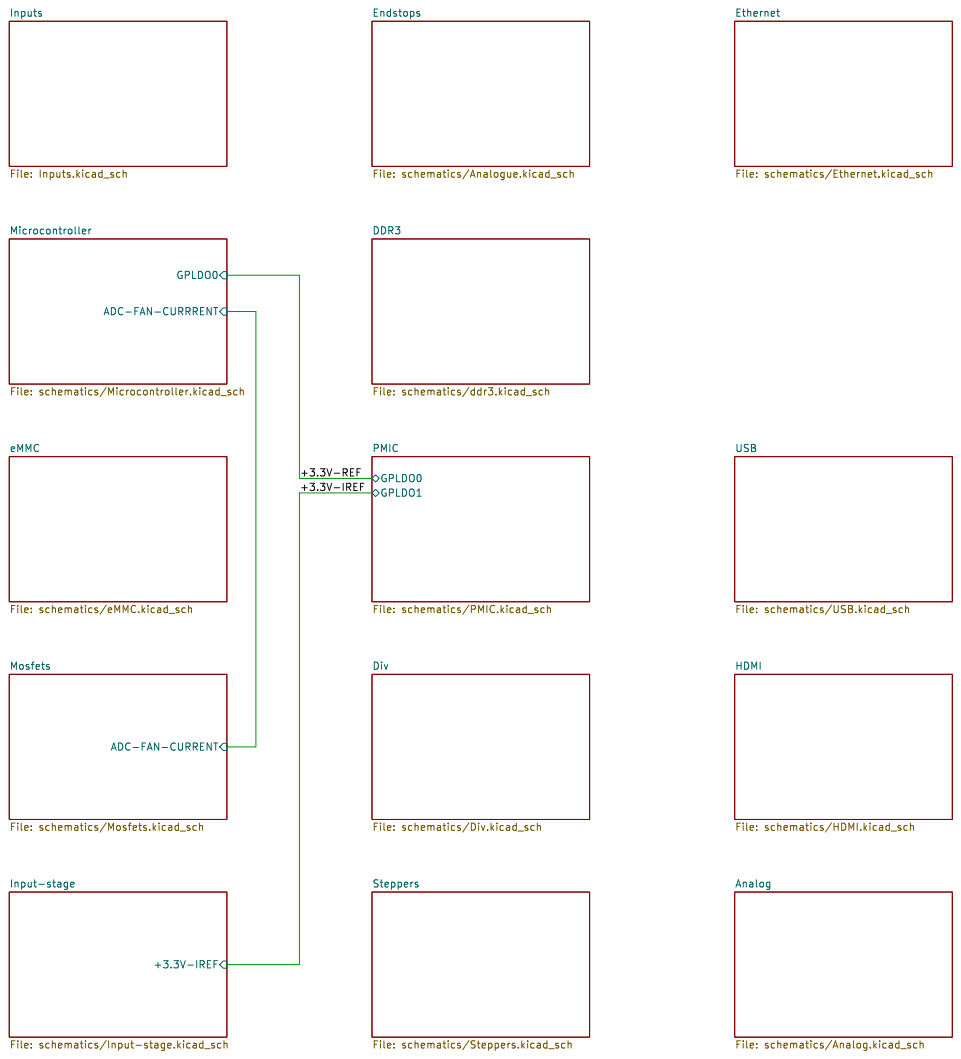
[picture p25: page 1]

Ethernet File: schematics/Ethernet.kicad_sch

Analog File: schematics/Analog.kicad_sch HDMI File: schematics/HDMI.kicad_sch GPLDO0 GPLDO1 PMIC

Input-stage File: schematics/Input-stage.kicad_sch

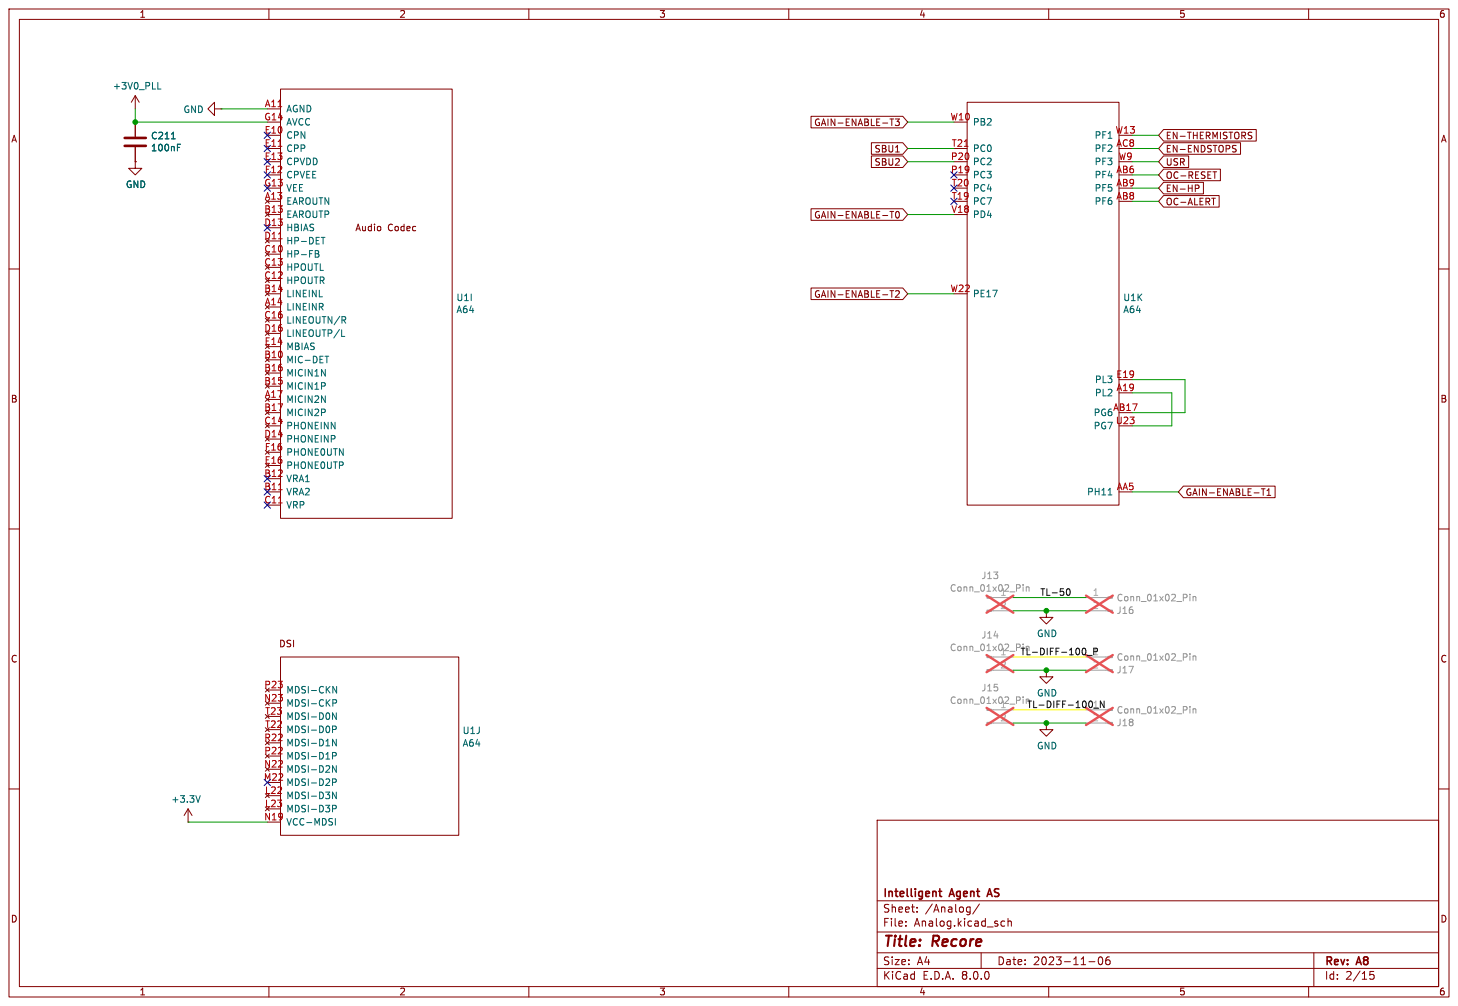
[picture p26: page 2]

EN-THERMISTORS GAIN-ENABLE-T1 USR OC-RESET EN-HP
OC-ALERT EN-ENDSTOPS
A64 GND 12

File: Analog.kicad_sch Sheet: /Analog/
Id: 2/15 Title: Recore

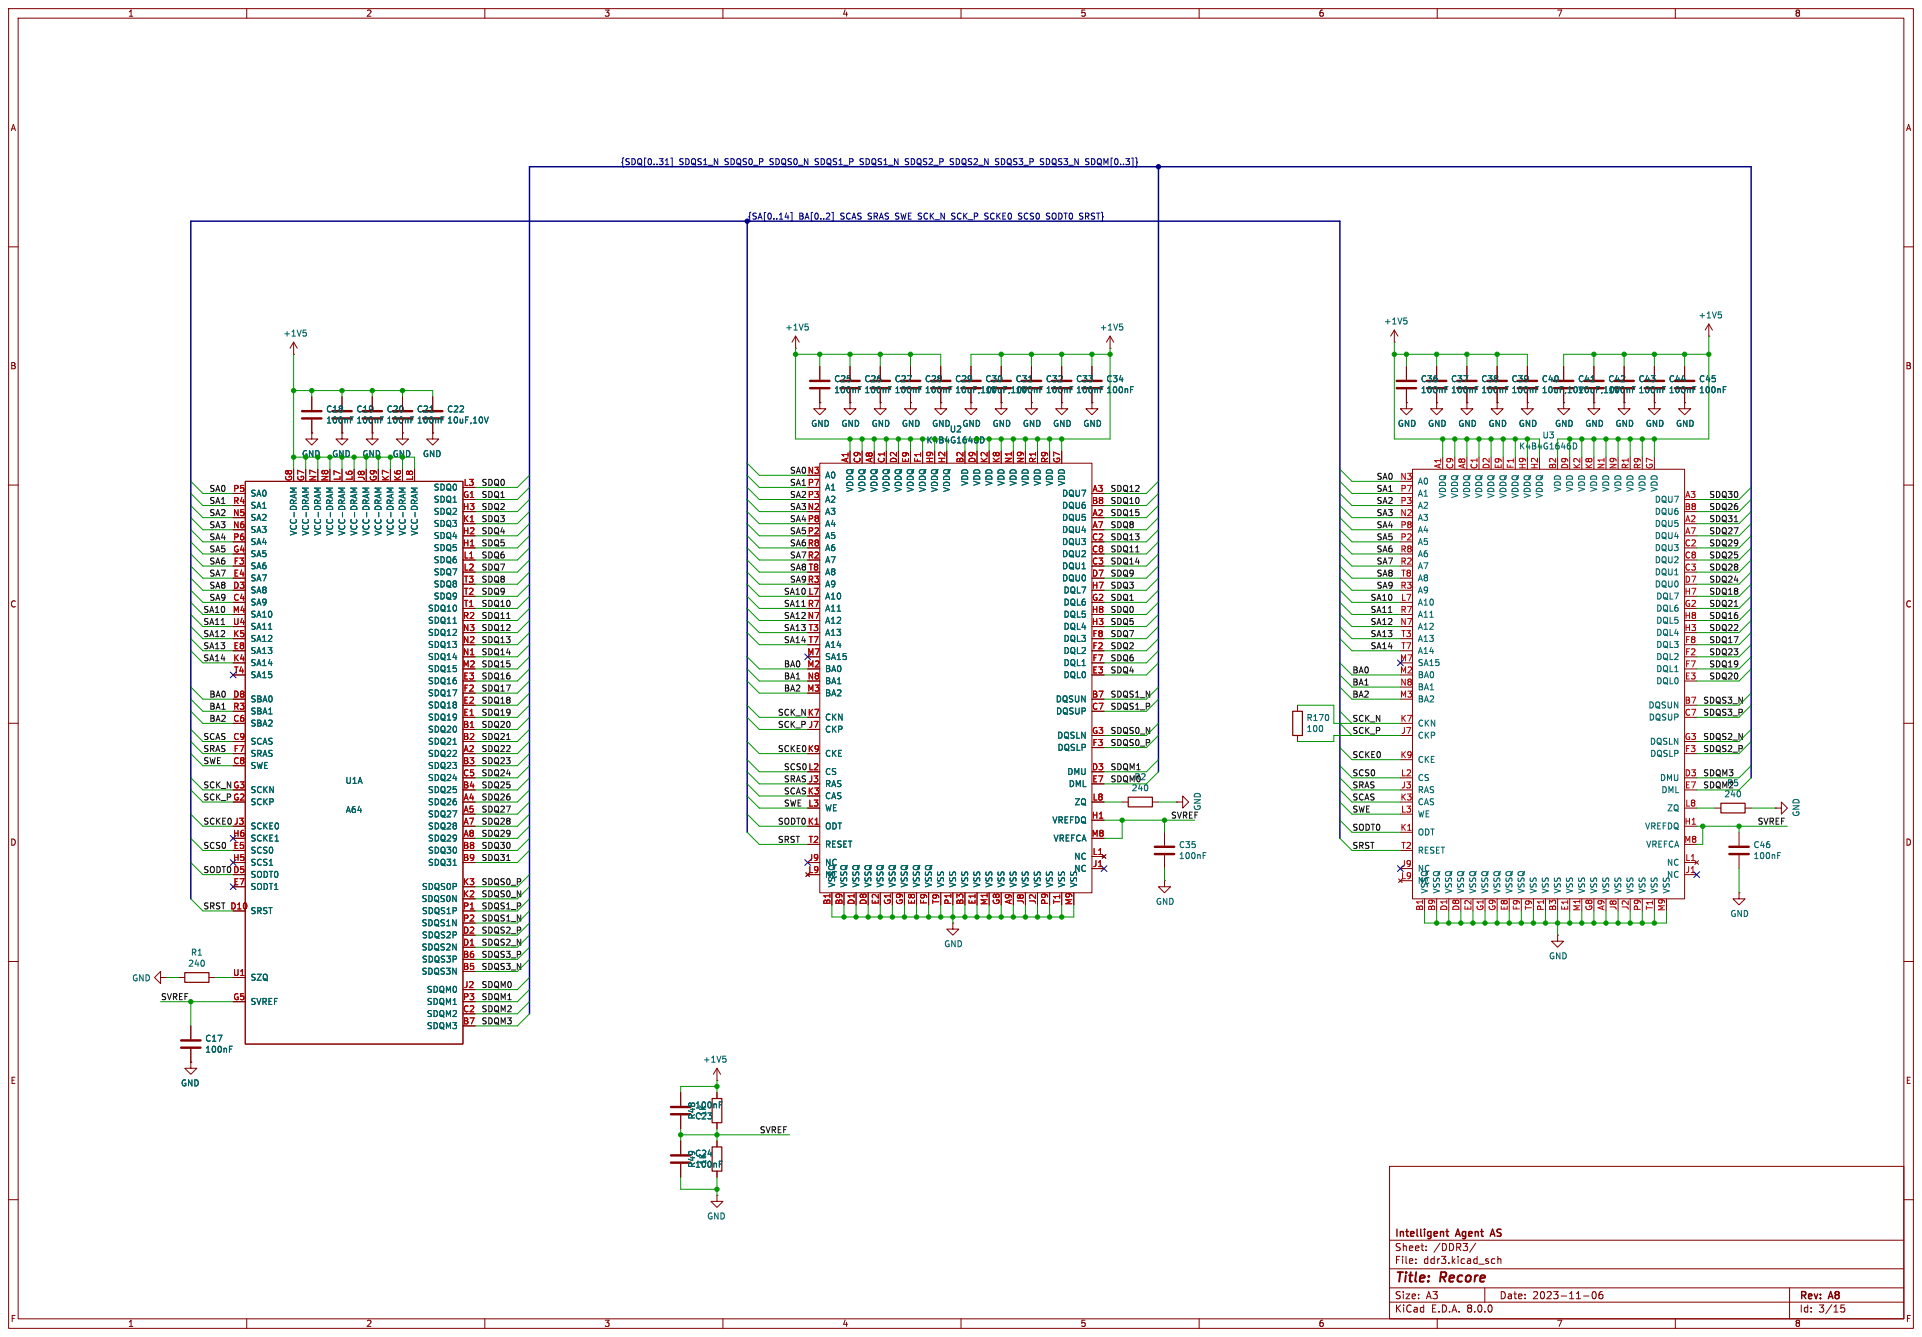
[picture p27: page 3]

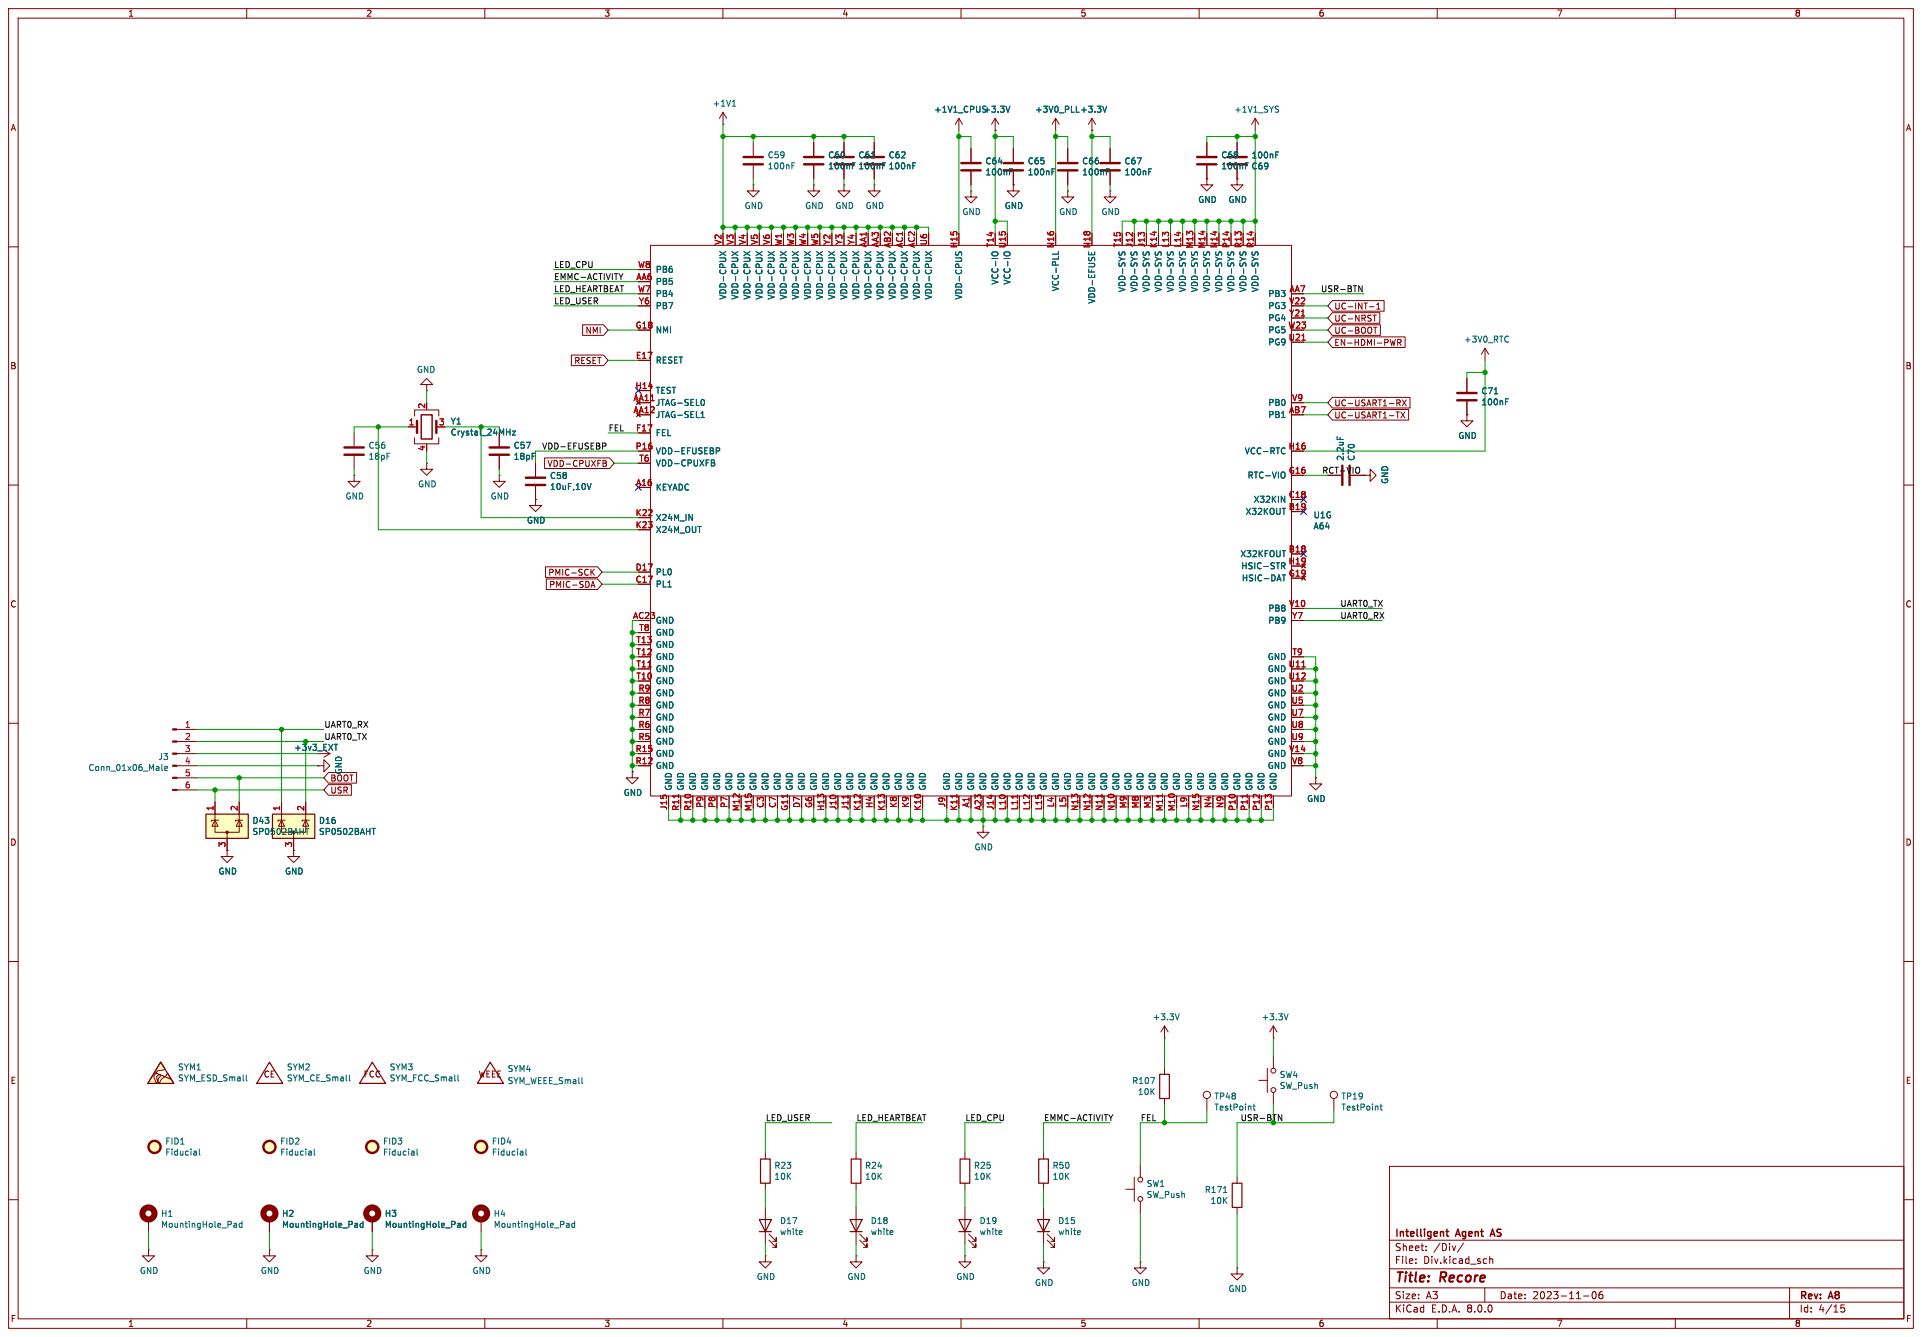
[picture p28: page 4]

GND
UART0_TX USR-BTN
UC-INT-1 EN-HDMI-PWR

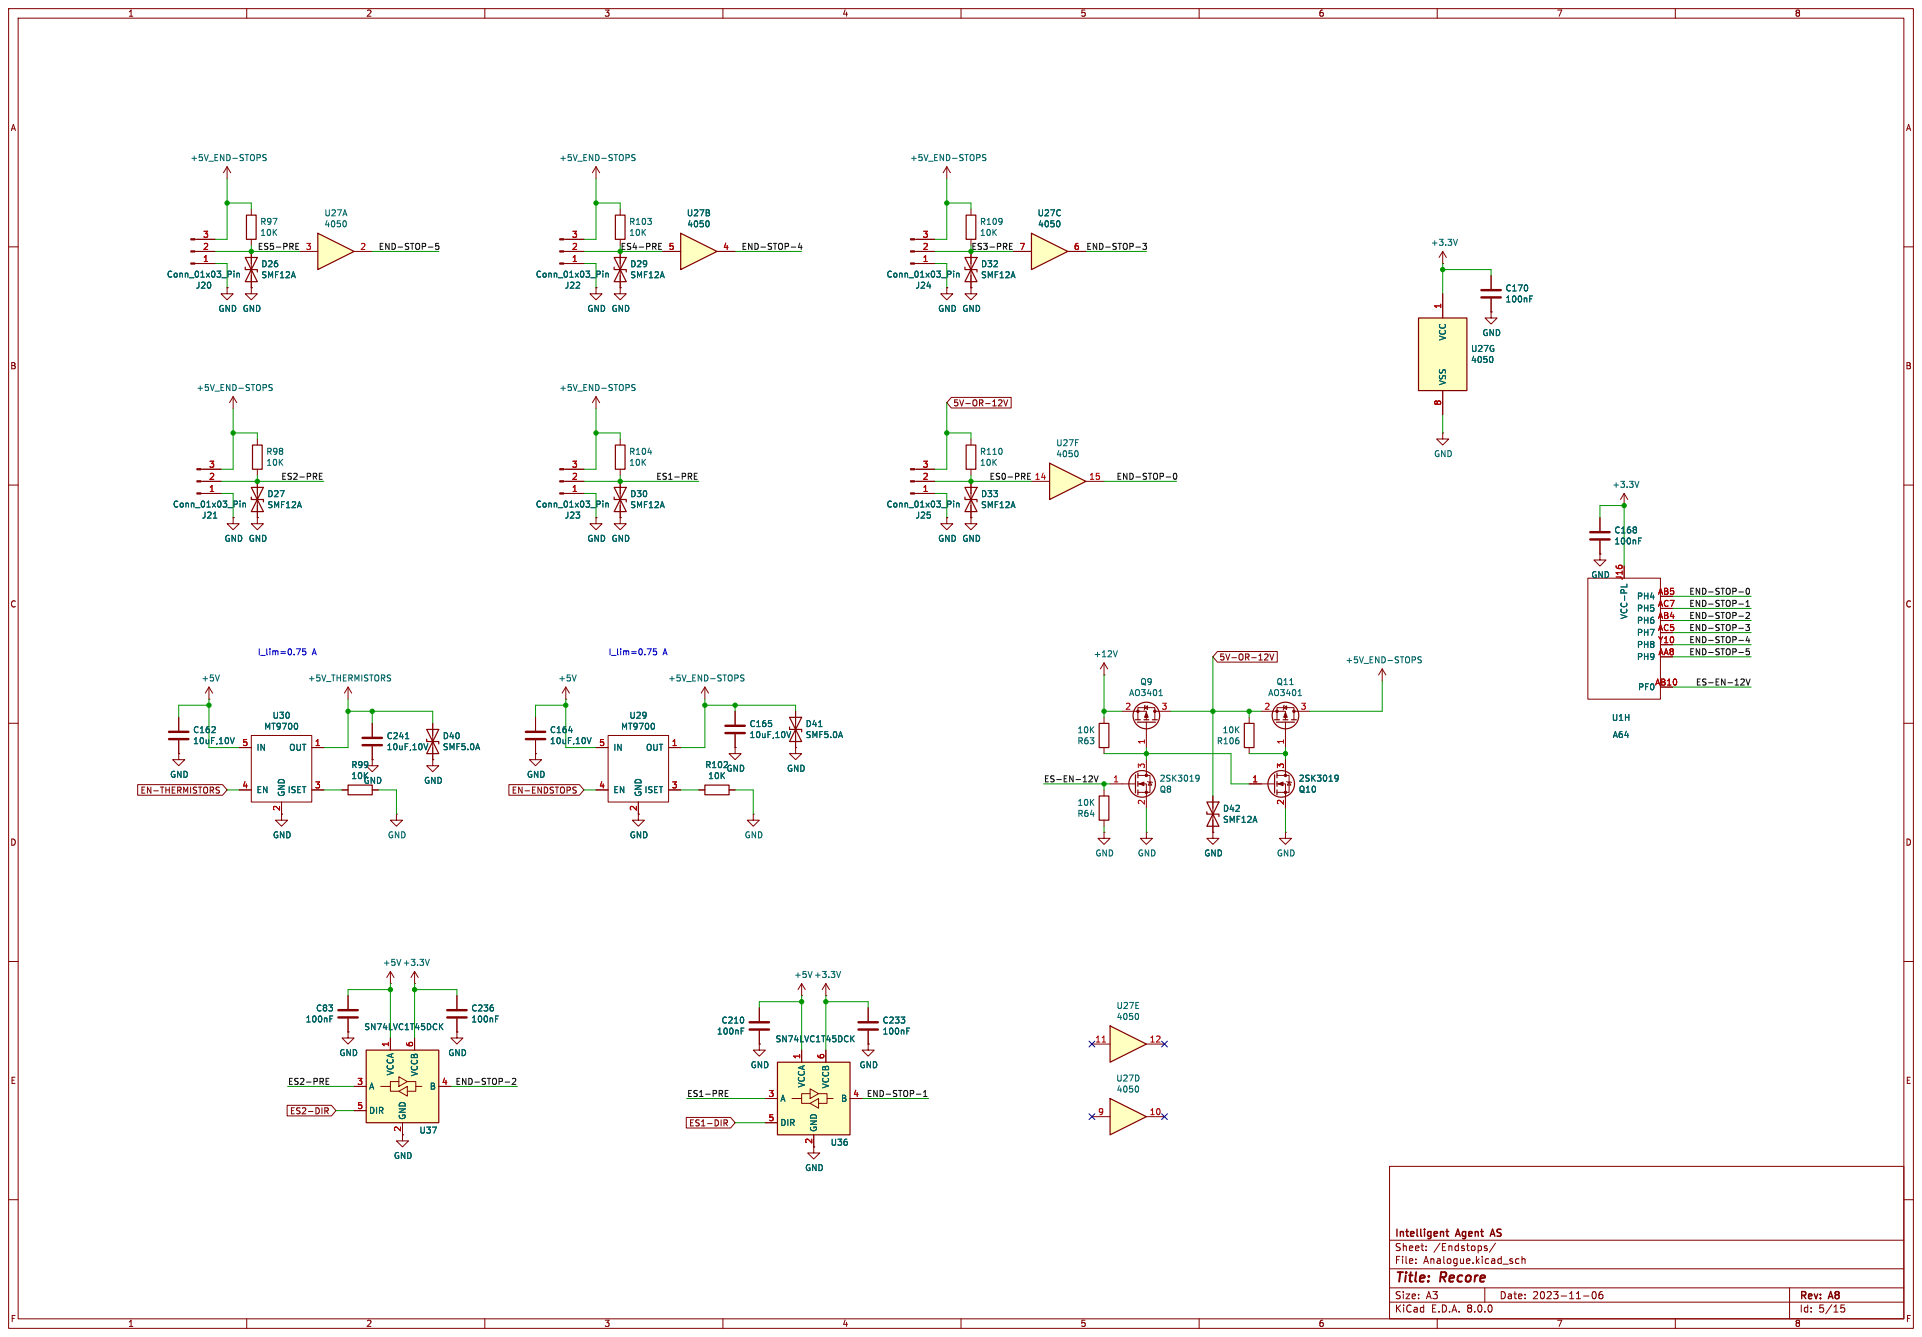
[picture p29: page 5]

END-STOP-4 END-STOP-5 ES2-PRE

File: Analogue.kicad_sch Sheet: /Endstops/
Id: 5/15 Title: Recore


4 GND GND GND GNDGND


2.49K4.7K R19 HTX2P D23 HSDA E20 HHPD E21 HTX2N E22 HTX1P E23 HCEC F21 HTX1N F22 HSCL G21 HTX0P G22 HTX0N G23 HTXCP H22 HTXCN H23 HVCC M16 U1B

File: HDMI.kicad_sch Sheet: /HDMI/
Id: 7/15 Title: Recore



PWR_FLAG
ADC-THERM-T0 GAIN-ENABLE-T2 ADC-THERM-T2


1 PA4 10 PA5 11 PA6 12 PA7 13 PB0 14 PB1 15 PB2 16 VDD 17 PA8 18 PA9 19 PF0 2 PA10 20 PA11 21 PA12 22 PA13 23 PA14 24 PA15 25 PB3 26 PB4 27 PB5 28 PB6 29 PF1 3 PB7 30 BOOT0 31 PB8 32 VSS 33 NRST 4 VDDA

ADC-THERM-T3 ADC-THERM-T0 ADC-THERM-T1 ADC-I ADC-THERM-T2 USER_LED

PWM-HEATER-E1 PWM-HEATER-E0 ADC-THERM-BOARD

PWM-HEATER-E2 PWM-HEATER-BED

File: Microcontroller.kicad_sch Sheet: /Microcontroller/
Id: 10/15 Title: Recore




1nF GND GND GND GND

100nF GND GND GND GND

File: Steppers.kicad_sch Sheet: /Steppers/


9 PAD 29 GND GND GND

8 Shield A10 Shield A11 Shield A12 VBUS

4 Shield A9 U31 AOZ8809NC 10 CH2 2 VN 3 CH3 4 CH4 5 NC 6 NC 7 VN 8 NC 9 CH1 1 GND

File: USB.kicad_sch Sheet: /USB/
Id: 14/15 Title: Recore


File: eMMC.kicad_sch Sheet: /eMMC/
Id: 15/15 Title: Recore

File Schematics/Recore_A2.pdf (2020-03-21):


Input-stage
Microcontroller schematics/Microcontroller.sch Ethernet schematics/Ethernet.sch Steppers

schematics/Input-stage.sch DDR3

schematics/ddr3.sch HDMI schematics/HDMI.sch

schematics/eMMC.sch Div

schematics/Steppers.sch Mosfets

schematics/Mosfets.sch Thermistors and endstops

schematics/Analogue.sch USB

Id: 1/13 Title: File: Recore.sch Sheet: /


ADC-THERM-BOARD GND GND GND GND

10K OC-RESET ENABLE-HIGH-POWER

Sheet: /Input-stage/
File: Input-stage.sch
Id: 2/13 Title:


0.1uF GND GND GND GND

10uF,10V GND GND GND GND

10uF,10V GND GND GND GND GND

Not using terination resistor

Id: 3/13 Title: File: ddr3.sch Sheet: /DDR3/


Id: 4/13 Title: File: HDMI.sch Sheet: /HDMI/ HTX2P D23 HSDA E20 HHPD E21 HTX2N E22 HTX1P E23 HCEC F21 HTX1N F22 HSCL G21 HTX0P G22 HTX0N G23 HTXCP H22 HTXCN H23 HVCC M16 U1B


EMMC_VDDI Route pins not through RFU

Id: 5/13 Title: File: eMMC.sch Sheet: /eMMC/


4 Y1Crystal_24MHz GND GND GND GND GND

UC-USART1-RX UC-USART1-TX


ADC-THERM-E0 ADC-THERM-E1 ADC-THERM-E2 ADC-THERM-BED

ADC-V
ADC-I ADC-THERM-BOARD

PWM-HEATER-E0 PWM-HEATER-E1 PWM-HEATER-E2 PWM-HEATER-BED

Id: 7/13 Title: File: Microcontroller.sch Sheet: /Microcontroller/ GND


TXCTL CLKIN MDC MDIO

Id: 8/13 Title: File: Ethernet.sch Sheet: /Ethernet/


GND GND GND GND GND GND GND GND


Id: 10/13 Title: File: Mosfets.sch Sheet: /Mosfets/


Sheet: /Thermistors and endstops/
File: Analogue.sch
Id: 11/13 Title:


USB_PWR_EN_0 USB_PWR_EN_1
0.1uF GND 10K R116 GND 10K R115 10K R114 10K R113 GND GND GND

8 Shield A10 Shield A11 Shield A12 VBUS 1 D- 2 D+ 3 GND

Id: 12/13 Title: File: USB.sch Sheet: /USB/


Id: 13/13 Title: File: PMIC.sch Sheet: /PMIC/ GND

















































































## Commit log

2020-03-21 Added schematic and boot files
2020-06-01 Updated heat test firmware
2020-10-26 Added Device tree for rev A3
2020-11-21 Added A4 schematic, cleaned up some
2020-11-21 Adding Calibration data for board 0009
2020-12-01 Updated calibration data on Recore A4 0009
2020-12-10 Added calibration data for Recore 0011
2020-12-11 Added calibration data for REcore A4 0012
2020-12-11 Added calibration data for 0013
2020-12-11 Added calibration data for Recore 0014
2020-12-11 Calibration data for 0015
2020-12-11 Adding calibration data for 0016
2020-12-11 Adding calibration data for 0017
2020-12-11 Adding calibration data for 0018
2020-12-13 Adding calibration data for 0019
2020-12-21 Added some older calibration files. Added A4 device tree
2020-12-28 Adding calibration data for 0020
2020-12-28 Adding calibration data for 0024
2020-12-28 Adding calibration data for 0023
2020-12-28 Adding calibration data for 0025
2020-12-28 Adding calibration data for 0026
2021-01-17 Rename device tree files to match existing setup
2021-05-25 Adding calibration data for 0002
2021-06-01 Adding calibration data for 0004
2021-06-01 Adding calibration data for 0104
2021-06-02 Adding calibration data for 0107
2021-06-02 Adding calibration data for 0108
2021-06-02 Adding calibration data for 0101
2021-06-02 Adding calibration data for 0109
2021-06-02 Adding calibration data for 0110
2021-06-02 Adding calibration data for 0111
2021-06-02 Adding calibration data for 0112
2021-06-03 Adding calibration data for 0113
2021-06-03 Adding calibration data for 0114
2021-06-03 Adding calibration data for 0115
2021-06-03 Adding calibration data for 0116
2021-06-03 Adding calibration data for 0117
2021-06-03 Adding calibration data for 0118
2021-06-03 Adding calibration data for 0119
2021-06-20 Adding calibration data for 0128
2021-06-20 Adding calibration data for 0129
2021-06-20 Adding calibration data for 0131
2021-06-20 Adding calibration data for 0132
2021-06-20 Adding calibration data for 0134
2021-06-20 Adding calibration data for 0137
2021-06-20 Adding calibration data for 0138
2021-06-20 Adding calibration data for 0139
2021-06-20 Adding calibration data for 0140
2021-06-21 Adding calibration data for 0130
2021-06-21 Adding calibration data for 0125
2021-06-22 Adding calibration data for 0121
2021-06-22 Adding calibration data for 0103
2021-06-22 Adding calibration data for 0105
2021-08-08 Adding A5 device tree
2021-09-03 Updated device tree, added dependencies
2021-09-28 Add schematic for rev A5, update makefile
2021-10-13 Adding calibration data for 0141
2021-12-16 Adding calibration data for 0202
2021-12-17 Adding calibration data for 0201
2021-12-22 Adding calibration data for 0203
2021-12-22 Adding calibration data for 0204
2021-12-22 Adding calibration data for 0205
2021-12-23 Adding calibration data for 0206
2021-12-23 Adding calibration data for 0207
2021-12-23 Adding calibration data for 0208
2021-12-23 Adding calibration data for 0209
2021-12-23 Adding calibration data for 0211
2021-12-23 Adding calibration data for 0212
2021-12-23 Added Rev A6 schematics
2021-12-31 Adding calibration data for 0214
2021-12-31 Adding calibration data for 0215
2021-12-31 Adding calibration data for 0216
2021-12-31 Adding calibration data for 0217
2021-12-31 Adding calibration data for 0218
2021-12-31 Adding calibration data for 0219
2022-01-05 Adding calibration data for 0220
2022-01-10 Adding calibration data for 0223
2022-01-10 Adding calibration data for 0225
2022-01-10 Adding calibration data for 0224
2022-01-10 Adding calibration data for 0227
2022-01-10 Adding calibration data for 0228
2022-01-10 Adding calibration data for 0229
2022-01-10 Adding calibration data for 0230
2022-01-10 Adding calibration data for 0231
2022-01-10 Adding calibration data for 0232
2022-01-12 Adding calibration data for 0226
2022-01-17 Adding calibration data for 0210
2022-01-17 Adding calibration data for 0235
2022-01-17 Adding calibration data for 0236
2022-01-17 Adding calibration data for 0237
2022-01-17 Adding calibration data for 0239
2022-01-17 Adding calibration data for 0240
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2022-08-15 Add missing calibration file
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2023-07-11 Add more 3D files
    [Relit_A0.step, Remove_A1.step, Restep_A1.step]
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2024-05-08 Added din rail mounts for Rebase A0
    [Rebase_A0_din-rail-holders.step]
2024-05-14 Added Rebase and cover with lid
    [Rebase_A0-ABS-cover.step, Rebase_A0-acrylic-lid.step, Rebase_A0.step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]
2024-05-14 Update din mount for Rebase. It was the wrong model.
    [Rebase_A0_din-rail-holders.step]
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2025-03-17 Added the step and FreeCad files
    [Clamps.FCStd, Wires-1-stepper.step, Wires-2xUSB-HDMI-2xFan.step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]
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2026-09-04 Make SerialNumber match the filename in 12 calibration files
    The A6 in the test rig is physically 0288 and carries
    Recore_A6_0288.json - every voltage in that file matches what the board
    reports live, and none match 0286's - but its SerialNumber field said
    0286. So the same board answered 0288 under Reflash
    (get-recore-serial-number) and 0286 under Rebuild (get-recore-config,
    which echoes this field), and the rig's identity check, which spans both
    boots, could not be satisfied by either value.
    Thirteen files disagree with their filename. Which identifier is
    authoritative is settled per file by collision, not by assumption:
    ten of them claim a serial that another file already claims AND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
2026-09-05 Recore_A8_0463: SerialNumber 0462 -> 0463
    Confirmed against the physical board, which is the only one of these
    verified that way: the sticker on the underside reads 0463, and the board
    itself answers 0463 from get-serial-number while get-recore-config - which
    reads this file - answers 0462.
    That mismatch is not cosmetic. The test rig identifies boards by serial,
    so a board carrying someone else's number is refused by its own cell.
    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
